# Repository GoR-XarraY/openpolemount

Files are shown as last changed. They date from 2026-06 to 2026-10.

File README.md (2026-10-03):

# OpenPoleMount





**An open-source, 3D-printable universal equipment cradle — and an open mounting standard for home IV poles.**

### 🎉 Certified Open Source Hardware

Every cradle in the line is certified by the [Open Source Hardware Association](https://certification.oshwa.org/):

| | Hardware | OSHWA UID | Certified |
|---|---|---|---|
| [OSHW US002864](https://certification.oshwa.org/us002864.html) | IV Pole Cradle v3 (current) | [US002864](https://certification.oshwa.org/us002864.html) | 2026-10-03 |
| [OSHW US002863](https://certification.oshwa.org/us002863.html) | IV Pole Cradle v2 (Universal Holder) | [US002863](https://certification.oshwa.org/us002863.html) | 2026-10-03 |
| [OSHW US002862](https://certification.oshwa.org/us002862.html) | IV Pole Accessory Box (v1) | [US002862](https://certification.oshwa.org/us002862.html) | 2026-10-03 |
| [OSHW US002834](https://certification.oshwa.org/us002834.html) | IV Pole Cradle (first listing) | [US002834](https://certification.oshwa.org/us002834.html) | 2026-07-10 |

OSHWA certifies that the design is open (public sources, open licenses). It is not a
safety or medical certification. Details: [openpolemount.com/certification](https://openpolemount.com/certification/)

> **This is not a business — it's an open-source hardware project.** Every file is
> free. The goal is that anyone who needs a cradle can print one themselves. A
> print-on-demand option exists so people without a printer aren't left out.

> ⚠️ **NOT A MEDICAL DEVICE — REFERENCE DESIGN ONLY.** OpenPoleMount is
> general-purpose mounting hardware provided for informational and educational
> purposes. It is **not** intended to deliver, control, or support medication or
> therapy, and it has **not** been evaluated or cleared by the FDA or any
> regulatory body. See [DISCLAIMER.md](DISCLAIMER.md) before use.

---

## What It Is

OpenPoleMount is a printed cradle that clamps to a standard home IV pole to hold
equipment. The mounting section — the **OpenPoleMount block** — is an open
standard, so any community-designed accessory can attach to any compatible home
IV pole.

The project began when a home-care caregiver couldn't source a mounting cradle
and printed their own. The files are shared freely so others can do the same.

## Versions

**v3 — current, recommended.** A smaller, more form-fitting cradle refined from
user feedback, built around the OpenPoleMount block standard. The cradle holds
equipment on the pole with the front face accessible, and a printed T-handle
thumbscrew clamps it to a standard home IV pole.

> v3's print files are now available — download the
> [v3 STL](https://github.com/GoR-XarraY/openpolemount/raw/main/stl/OpenPoleMount_IV-Pole_v3.stl)
> or see [openpolemount.com/iv-pole-v3](https://openpolemount.com/iv-pole-v3/) for details.

**v2 — universal device holder.** Fully released and print-ready. Documented as a
universal holder (may fit a range of equipment; no confirmed compatibility list
yet — fit reports welcome). This is the version currently available via
print-on-demand.

**v1 — legacy.** Best repurposed as a pole-mounted accessory box that mounts
below the cradle.

## Specifications

Printed-part dimensions and a starting load rating. **Match your equipment's own
size and weight to these figures before printing** — if it fits the envelope, it
fits the cradle.

| Part | Printed size (L × W × H) | Load rating* |
|---|---|---|
| Equipment cradle v3 | ~125 × 100 × 66 mm | up to ~1.4 kg (3 lb) |
| Equipment cradle v2 | ~126 × 105 × 65 mm | up to ~1.4 kg (3 lb) |
| Pole mounting block | ~60 × 58 × 48 mm | — |

\* *Starting point, not a guarantee. Actual capacity depends on your material,
print settings, and print quality — see the [Print Guide](https://openpolemount.com/iv-pole-v3/print-settings/)
and [DISCLAIMER.md](DISCLAIMER.md). Verify safe support of your own load before use.*

## Community Fit Reports

> The notes here are **user-reported, not manufacturer claims, and not verified
> for any medical use.** OpenPoleMount makes no compatibility guarantee. Confirm
> fit, load suitability, and safety yourself before any use, and consult your
> healthcare provider before using any mount with medical equipment.

Makers have reported that the v3 and v2 form factors fit some home infusion
equipment (including units labeled Curlin CMS6000). We do not maintain or
guarantee a compatibility list. To share a fit report, please
[open an issue](https://github.com/GoR-XarraY/openpolemount/issues).

## Files

| File | Description |
|---|---|
| [`stl/OpenPoleMount_IV-Pole_v3.stl`](https://github.com/GoR-XarraY/openpolemount/raw/main/stl/OpenPoleMount_IV-Pole_v3.stl) | **Equipment cradle v3** — current design, form-fitted (available now) |
| `stl/OpenPoleMount_IV-Pole_v2.stl` | Equipment cradle v2 — universal device holder, available now (print 1x) |
| `stl/thumbscrew_v14_flat_Thandle.stl` | Thumbscrew for pole attachment (print 1x) |
| `stl/OpenPoleMount_IV-Pole_v1.stl` | v1 — legacy; best used as a pole-mounted accessory box |
| [`source/`](source/) | Native editable source files — Blender `.blend` for every design |

## Quick Start

1. **Download** the STL files from [Releases](https://github.com/GoR-XarraY/openpolemount/releases/latest)
2. **Print** the v3 cradle in PLA — see the [v3 Print Guide](https://openpolemount.com/iv-pole-v3/print-settings/); the [v2 Print Guide](https://openpolemount.com/iv-pole-v2/print-settings/) is available too
3. **Assemble** — see the [v3 Assembly Guide](https://openpolemount.com/iv-pole-v3/assembly/)
4. **Read the disclaimer** — [DISCLAIMER.md](DISCLAIMER.md)

No printer? v3 (PETG) and v2 (PLA) can be printed on demand and shipped via
Slant 3D / Teleport — see [openpolemount.com/order](https://openpolemount.com/order/).

## Website & Documentation

**[openpolemount.com](https://openpolemount.com)** — full documentation, print
guide, assembly instructions, safety information

## Licensing

| Asset | License |
|---|---|
| Hardware (STL, STEP, CAD files) | [CERN-OHL-W-2.0](LICENSE) — derivatives must stay open |
| Documentation (docs/, README, images) | [CC-BY-SA-4.0](LICENSE-docs) |

## Contributing

Have an idea for a new IV pole accessory? See [CONTRIBUTING.md](CONTRIBUTING.md).

The OpenPoleMount block mounting standard is designed so any community-designed
accessory can attach to any compatible IV pole mount.

## Community

- [Printables listing](https://www.printables.com) *(link coming soon)*
- Open an [Issue](https://github.com/GoR-XarraY/openpolemount/issues) with questions or problems

---

*OpenPoleMount is an independent open source project. It is not affiliated with
Curlin Medical, Smiths Medical, Moog, or any IV pump manufacturer.*

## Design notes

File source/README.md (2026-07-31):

# Source CAD Files

This folder contains the **native, editable source files** for the OpenPoleMount
hardware designs. The designs are made in [Blender](https://www.blender.org/) —
free, open-source software — so anyone can open, edit, and remix these files
without buying CAD software.

## Files

| File | Design |
|---|---|
| `OpenPoleMount_IV-Pole_v3.blend` | IV Pole Cradle v3 (current, form-fitting) |
| `OpenPoleMount_IV-Pole_v2.blend` | IV Pole Cradle v2 (universal holder) |
| `OpenPoleMount_IV-Pole_v1.blend` | v1 (accessory box) |
| `OpenPoleMount_Pole_Mounting_Block_V1.blend` | Pole Mounting Block |
| `OpenPoleMount_Pole_THandle_Thumbscrew.blend` | T-handle thumbscrew (shared by all designs) |

The ready-to-print STL meshes exported from these sources live in [`stl/`](../stl/).

## Why Source Files Matter

Publishing editable source files (not just STL) is a requirement of true open
source hardware. STL files are like a PDF — anyone can read them but nobody can
easily edit them. These `.blend` files are the original documents — fully editable.

This satisfies the editable-source expectation of
[OSHWA certification](https://certification.oshwa.org), using an open-source
toolchain end to end.

## Editing

Open in Blender 3.x or newer. Units are millimeters at real-world scale — verify
scale before exporting STL for print (File → Export → STL, apply modifiers).
Derivatives are welcome under the hardware license
([CERN-OHL-W-2.0](https://cern-ohl.web.cern.ch/)) — see
[Contributing](https://openpolemount.com/contributing/).

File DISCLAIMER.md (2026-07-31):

# Disclaimer and Liability Notice

## This Is a Reference Design, Not a Medical Device

OpenPoleMount is an open-source reference design for a 3D-printable IV pole
mounting accessory. It is **not** a medical device, and it has **not** been
evaluated, cleared, or approved by the U.S. Food and Drug Administration (FDA)
or any other regulatory body.

## No Warranty

THE OPENPOLEMOUNT DESIGNS, FILES, AND DOCUMENTATION ARE PROVIDED "AS IS,"
WITHOUT WARRANTY OF ANY KIND, EXPRESS OR IMPLIED, INCLUDING BUT NOT LIMITED TO
WARRANTIES OF MERCHANTABILITY, FITNESS FOR A PARTICULAR PURPOSE, SAFETY,
REGULATORY COMPLIANCE, OR NON-INFRINGEMENT.

## Your Responsibility

By using, printing, assembling, or deploying any OpenPoleMount design, you
acknowledge and agree that:

1. **You are solely responsible** for verifying the mechanical integrity,
   dimensional accuracy, material suitability, and safe use of any parts
   you print or assemble.

2. **You must verify that printed parts can safely support the intended load.**
   A typical home infusion device with a full IV bag weighs approximately
   1.4 kg (3 lb). Parts must be printed with appropriate materials and infill to
   safely support the weight of whatever you mount. See the [Print Guide](https://openpolemount.com/iv-pole-v3/print-settings/)
   for minimum recommended settings — these are starting points, not guarantees.

3. **This design is a reference only.** It has not been load-tested under
   clinical conditions. Real-world loads, print quality variations, material
   degradation, and installation errors can all affect safety.

4. **Consult a qualified healthcare professional** before using any accessory
   with medical equipment or in a clinical or home-care setting.

## No Medical Advice

Nothing in this project constitutes medical advice, clinical guidance, or a
recommendation for patient care. Always follow your healthcare provider's
instructions for the safe use of your infusion pump and IV pole.

## Limitation of Liability

To the maximum extent permitted by law, the OpenPoleMount project contributors
shall not be liable for any direct, indirect, incidental, special, consequential,
or punitive damages arising from the use or inability to use these designs,
including but not limited to personal injury, equipment damage, or treatment
interruption.

## Regulatory Note

Depending on your jurisdiction and intended use, 3D-printed accessories for
medical equipment may be subject to local regulations. You are responsible for
determining and complying with any applicable regulations in your area.

---

*If you have questions about safe use, consult your healthcare provider, infusion
pump manufacturer, or a licensed biomedical engineer.*

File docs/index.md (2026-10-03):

# OpenPoleMount

**An open-source, 3D-printable universal equipment cradle — and an open mounting standard for home IV poles.**

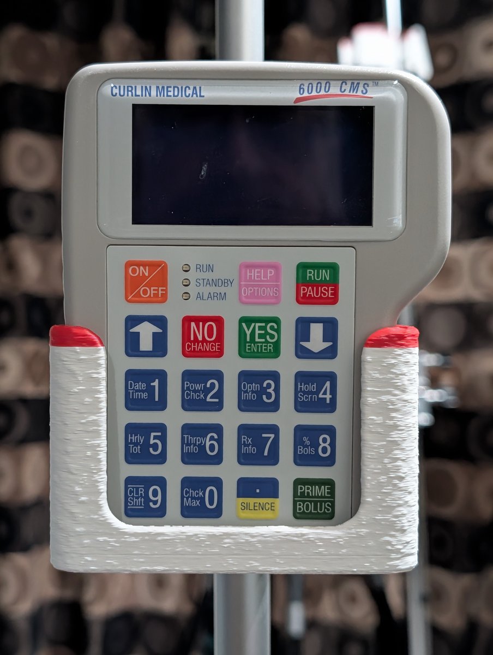
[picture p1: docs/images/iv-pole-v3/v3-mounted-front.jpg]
Compact device seated in the OpenPoleMount v3 cradle on a home IV pole

*The current design — **IV Pole Cradle v3** — a smaller, more form-fitting cradle, refined from feedback on v2.*

<div style="display:flex;flex-wrap:wrap;align-items:center;gap:1rem 1.5rem;padding:1.25rem 1.4rem;margin:1.5rem 0;border-radius:12px;border:2px solid #FF4444;background:var(--md-code-bg-color);">
  <a href="certification/" style="flex:none;display:block;background:#fff;border-radius:10px;padding:10px;">
    OSHW certification mark US002864
  </a>
  <div style="flex:1 1 18rem;">
    <div style="font-size:1.35rem;font-weight:800;line-height:1.25;">🎉 Certified Open Source Hardware</div>
    <div style="margin:0.35rem 0 0.6rem;color:var(--md-default-fg-color--light);">
      The v3 cradle, the v2 universal holder and the v1 accessory box are all certified by the
      <strong>Open Source Hardware Association</strong> —
      <a href="https://certification.oshwa.org/us002864.html">US002864</a>,
      <a href="https://certification.oshwa.org/us002863.html">US002863</a>,
      <a href="https://certification.oshwa.org/us002862.html">US002862</a> and
      <a href="https://certification.oshwa.org/us002834.html">US002834</a>.
    </div>
    <a href="certification/" class="md-button md-button--primary">See the certifications</a>
  </div>
</div>

---

!!! note "This is not a business — it's an open-source hardware project"
    Every file here is free. The goal is simple: that anyone who needs a cradle can
    **print one themselves**, and that the community can build on the design. There is
    nothing to buy to use this project. A print-on-demand option exists so people
    **without a printer** aren't left out.

!!! warning "Reference Design — Not a Medical Device"
    These files are provided for informational and educational purposes only.
    This design is not FDA-cleared or approved. You are responsible for
    verifying the mechanical integrity of any printed parts before use.
    [Read the full disclaimer →](safety.md)

---

## The Problem

Mounting cradles for home infusion equipment can be hard to source, and the bag
alternative many pharmacies send is awkward for anyone who isn't an experienced
nurse. Many home-healthcare users need a reliable, easy-to-use mounting solution
now.

## The Solution — IV Pole Cradle v3

An open-source cradle that any maker can print and any user can assemble.
**v3 is the current, recommended design**: a smaller, more form-fitting redesign
built from feedback on v2 — equipment seats in the pocket with the front face
accessible, and a printed T-handle thumbscrew clamps it to a standard home IV
pole. The mounting section is built as the **[OpenPoleMount
block](mounting-block/index.md)** — the project's foundational component and a
universal standard for any accessory on a home IV pole.

[See all v3 photos & details →](iv-pole-v3/index.md){ .md-button .md-button--primary }

### The v3 model

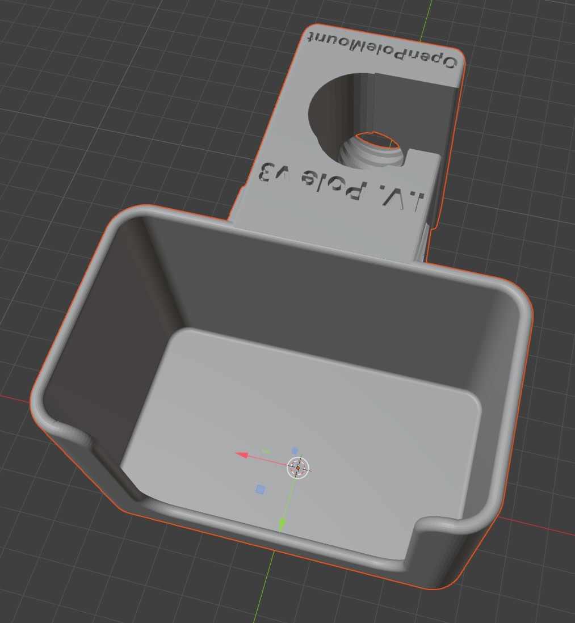
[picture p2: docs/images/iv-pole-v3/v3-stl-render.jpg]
IV Pole Cradle v3 — 3D render, form-fitting equipment pocket at left, U-shaped pole channel at right

*IV Pole Cradle v3 — form-fitting equipment pocket at left, U-shaped pole channel and thumbscrew boss at right, "I.V. Pole v3" embossed on the body.*

---

## Get the v3 cradle

The whole point of this project is **open-source 3D printing**. Printing it
yourself is the primary path — it's free, and you control the material and quality.

<div style="padding:2rem;background:var(--md-code-bg-color);border-radius:8px;border-left:5px solid var(--md-primary-fg-color);margin:1.5rem 0;">
  <div style="font-size:1.35rem;font-weight:800;margin-bottom:0.5rem;">🖨️ Print it yourself — free & open source</div>
  <div style="font-size:0.95rem;color:var(--md-default-fg-color--light);margin-bottom:1.25rem;max-width:48rem;">
    Download the [v3 STL files](https://github.com/GoR-XarraY/openpolemount/raw/main/stl/OpenPoleMount_IV-Pole_v3.stl) and print on any FDM printer. Tested
    settings carried over from v1/v2 in PLA. Two parts: the cradle body and the
    T-handle thumbscrew — no extra hardware needed.
  </div>
  <a href="iv-pole-v3/print-settings/" style="display:inline-block;padding:0.6rem 1.5rem;background:var(--md-primary-fg-color);color:white;border-radius:4px;text-decoration:none;font-size:1rem;font-weight:700;">Print Guide (v3) →</a>
</div>

<div style="padding:1.25rem 1.5rem;background:var(--md-code-bg-color);border-radius:8px;border-left:4px solid #888;margin:1rem 0;">
  <div style="font-size:1rem;font-weight:700;margin-bottom:0.35rem;">📦 No printer nearby? Order a print.</div>
  <div style="font-size:0.875rem;color:var(--md-default-fg-color--light);margin-bottom:0.85rem;">
    The <strong>v3</strong> cradle + thumbscrew can be printed in PETG and shipped
    via <strong>Slant 3D / Teleport</strong> (v2 in PLA too) — a fallback for people
    without printer access.
  </div>
  <a href="order/" style="display:inline-block;padding:0.45rem 1.1rem;background:#555;color:white;border-radius:4px;text-decoration:none;font-size:0.9rem;font-weight:600;">Order a print →</a>
</div>

## Download STL Files

[Download STL Files (latest release)](https://github.com/GoR-XarraY/openpolemount/releases/latest){ .md-button .md-button--primary }
[View on GitHub](https://github.com/GoR-XarraY/openpolemount){ .md-button }

| File | Purpose | Print |
|---|---|---|
| [`OpenPoleMount_IV-Pole_v3.stl`](https://github.com/GoR-XarraY/openpolemount/raw/main/stl/OpenPoleMount_IV-Pole_v3.stl) | **v3 cradle body** — current design, form-fitted pocket | 1× |
| [`OpenPoleMount_IV-Pole_v2.stl`](https://github.com/GoR-XarraY/openpolemount/raw/main/stl/OpenPoleMount_IV-Pole_v2.stl) | v2 cradle body — universal device holder, available now | 1× |
| [`thumbscrew_v14_flat_Thandle.stl`](https://github.com/GoR-XarraY/openpolemount/raw/main/stl/thumbscrew_v14_flat_Thandle.stl) | T-handle thumbscrew for pole attachment | 1× |

## Getting Started

1. **[See the v3 cradle →](iv-pole-v3/index.md)** — photos, model, and details
2. **[Print it yourself →](iv-pole-v3/print-settings.md)** — settings, orientation, checklist
3. **[Assemble it →](iv-pole-v3/assembly.md)** — step-by-step mounting (no tools)
4. **[Safety & Disclaimer →](safety.md)** — read before use

## Designed For

| Component | Description |
|---|---|
| Equipment | A compact device that fits the pocket envelope (~125 × 100 × 66 mm, up to ~1.4 kg / 3 lb) |
| Pole | Standard home IV pole (~25 mm / 1 inch diameter) |
| Attachment | Printed T-handle thumbscrew (included in download) |

## Open Source — Build On It

All designs are released under [CERN-OHL-W-2.0](https://cern-ohl.web.cern.ch/) —
any modifications must stay open source. Documentation is under
[CC-BY-SA-4.0](https://creativecommons.org/licenses/by-sa/4.0/). This is community
hardware: improvements, remixes, and new accessories are the goal.

**[Contribute a new accessory →](contributing.md)**

---

## Looking for v2?

**v2** is still fully released and print-ready — it's now documented as a
**universal device holder**: its more open pocket may fit a range of similar-sized
equipment, though we don't yet have a confirmed compatibility list. It's also the version currently available via print-on-demand order.

**[About the v2 universal holder →](iv-pole-v2/index.md)**

## Looking for v1?

The original **v1** print is still available, but it's **not functional as an
equipment cradle** — the device's buttons and screen are not accessible when it's
seated in v1. v1 is best repurposed as an **accessory box that mounts on the pole
below the cradle** — for alcohol wipes, spare caps, tubing, or other small supplies.

**[About the v1 accessory box →](print-settings.md)**

---

*OpenPoleMount is an independent open-source project. It is not affiliated with
Curlin Medical, Smiths Medical, or any IV pump manufacturer.*

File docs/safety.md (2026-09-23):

# Safety & Disclaimer

## ⚠️ This Is a Reference Design, Not a Medical Device

OpenPoleMount is an open-source reference design. It is **not** a medical device
and has **not** been evaluated, cleared, or approved by the FDA or any other
regulatory body.

**By printing or using this design, you accept full responsibility for verifying
its safety and suitability for your specific situation.**

---

## Full Disclaimer

THE OPENPOLEMOUNT DESIGNS, FILES, AND DOCUMENTATION ARE PROVIDED "AS IS,"
WITHOUT WARRANTY OF ANY KIND. THE OPENPOLEMOUNT PROJECT AND ITS CONTRIBUTORS
MAKE NO WARRANTIES AND ACCEPT NO LIABILITY FOR ANY USE OF THESE DESIGNS,
INCLUDING BUT NOT LIMITED TO PERSONAL INJURY, EQUIPMENT DAMAGE, OR TREATMENT
INTERRUPTION.

See [DISCLAIMER.md](https://github.com/GoR-XarraY/openpolemount/blob/main/DISCLAIMER.md)
for the complete legal disclaimer.

---

## Before First Use — Safety Checklist

Work through this checklist every time before mounting equipment:

**Print quality:**

- [ ] Parts printed to the recommended minimums — ≥1 mm walls, ≥1 mm top/bottom, ≥25% non-concentric infill (grid is fine) — see the [Print Guide](iv-pole-v3/print-settings.md)
- [ ] No visible layer delamination — parts do not flex or crack under firm hand pressure
- [ ] No significant warping — base and pole channel are flat and straight
- [ ] Thumbscrew threads are clean, smooth, and undamaged

**Fit and function:**

- [ ] Thumbscrew engages cleanly and holds firm under hand pressure
- [ ] Cradle mounted on pole — does not slide under firm downward push
- [ ] Device seats fully in the cradle without rocking or side movement
- [ ] Any tubing or cabling exits the device without creating tension on the mount

**Environment:**

- [ ] IV pole base is fully spread and stable on the floor
- [ ] Floor surface is stable (not sloped or slippery)
- [ ] Caregiver or nurse has reviewed the complete setup

---

## Who to Contact

| Question | Contact |
|---|---|
| Equipment use and care | Your equipment supplier or home health agency |
| IV pole setup | Your home health nurse |
| Print quality issues | [Open a GitHub issue](https://github.com/GoR-XarraY/openpolemount/issues) |
| Medical safety questions | Your healthcare provider |

---

## Regulatory Note

In the United States, the FDA regulates 3D-printed objects that are *marketed
as medical devices*. OpenPoleMount publishes open reference designs — it is
not marketed as a finished product or medical device.

However, regulations vary by jurisdiction and intended use. You are responsible
for understanding and complying with any applicable regulations in your area.

If you are a healthcare professional intending to use this design in a clinical
setting, please consult your institution's biomedical engineering department and
compliance officer before use.

---

*Last reviewed: 2026-07-30*

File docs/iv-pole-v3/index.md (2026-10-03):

---
title: IV Pole Mount v3
description: Open source 3D-printable form-fitting equipment cradle for home IV poles
image: images/iv-pole-v3/v3-og-image.jpg
---

# IV Pole Cradle v3

<div style="display:flex;align-items:center;gap:1rem;padding:0.9rem 1rem;margin:1rem 0 1.5rem;border-radius:10px;border:1px solid var(--md-default-fg-color--lightest);">
  <a href="https://certification.oshwa.org/us002864.html" style="flex:none;display:block;background:#fff;border-radius:8px;padding:8px;" title="OSHWA certificate US002864">
    OSHW certification mark US002864
  </a>
  <div><strong>Certified open source hardware</strong> — the IV Pole Cradle v3 is OSHWA certificate
  <a href="https://certification.oshwa.org/us002864.html">US002864</a>.
  <a href="../../certification/">About the certifications →</a></div>
</div>

**The current OpenPoleMount design — a smaller, more form-fitting cradle pocket,
based on feedback from people using v2.**

IV Pole Cradle v3 — 3D render, "I.V. Pole v3" and "OpenPoleMount" embossed on the mounting block
*IV Pole Cradle v3 — a tighter, form-fitting pocket (~125 x 100 x 66 mm printed), with the same U-shaped pole channel and thumbscrew boss as v2.*

---

!!! success "This is the design to print"
    **v3 is the recommended cradle.** It's a smaller, more form-fitting redesign of
    the pocket — built directly from feedback from people who printed v2 — while
    keeping the same pole channel and printed T-handle thumbscrew that clamps it to
    a standard home IV pole. It uses the `thumbscrew_v14_flat_Thandle.stl` thumbscrew
    and the OpenPoleMount block standard, same as v1 and v2.

    [**v2**](../iv-pole-v2/index.md) is still a good print — it's now documented as a
    **universal device holder** for other devices, since its more open
    pocket shape isn't as tightly fitted to any one device.

!!! success "v3 STL files are available now"
    The v3 print files are published and ready to print. Download the
    [v3 cradle STL](https://github.com/GoR-XarraY/openpolemount/raw/main/stl/OpenPoleMount_IV-Pole_v3.stl)
    directly, or see the [Print Guide](print-settings.md) for settings and required files.

## Installed Photos

<div style="display:grid;grid-template-columns:1fr 1fr;gap:1rem;margin:1.5rem 0;">
  <div>
    Equipment cradle v3 — front view, device seated
    <p style="font-size:0.85em;color:#666;margin-top:0.4rem;">Front — the device seats in the pocket with the front face accessible</p>
  </div>
  <div>
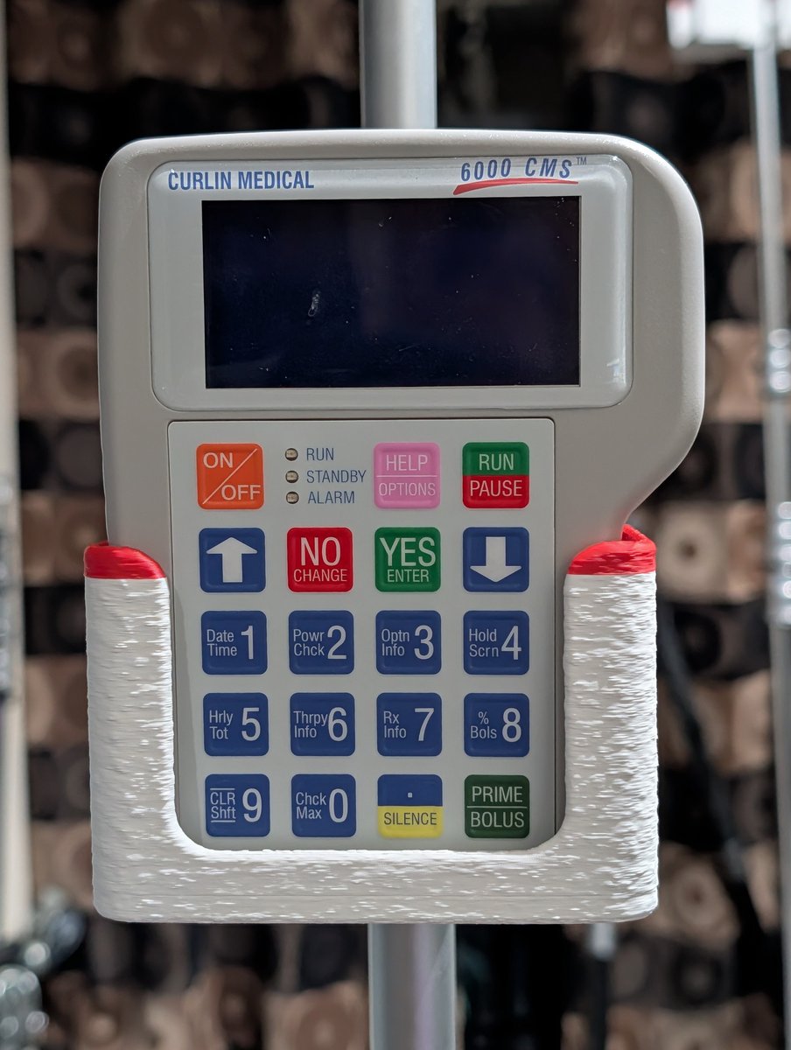
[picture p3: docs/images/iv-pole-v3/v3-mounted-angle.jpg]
V3 mount — 3/4 angle view
    
    <p style="font-size:0.85em;color:#666;margin-top:0.4rem;">3/4 angle — device in the form-fitting cradle pocket</p>
  </div>
  <div>
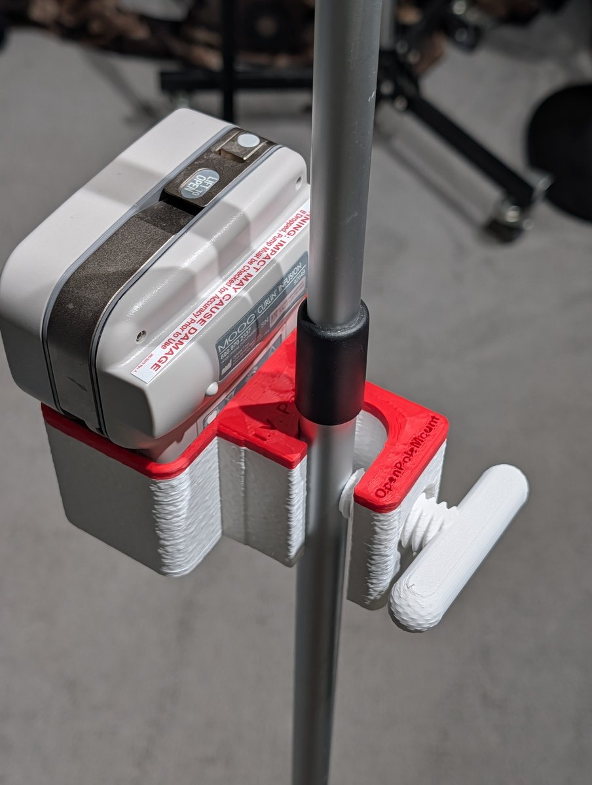
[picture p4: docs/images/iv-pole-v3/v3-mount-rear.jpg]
V3 mount — rear/underside with device cassette door
    
    <p style="font-size:0.85em;color:#666;margin-top:0.4rem;">Rear/underside — device cassette door, "I.V. Pole v3" / "OpenPoleMount" embossed on the block</p>
  </div>
  <div>
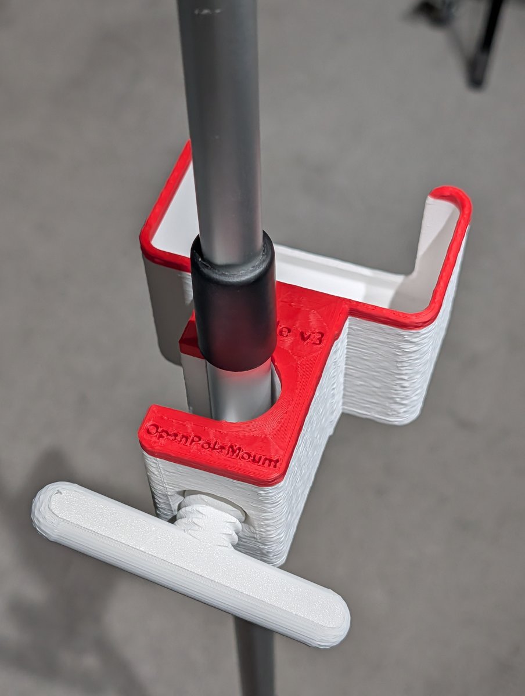
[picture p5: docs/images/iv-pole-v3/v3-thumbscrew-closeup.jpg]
T-handle thumbscrew close-up on V3 mount
    
    <p style="font-size:0.85em;color:#666;margin-top:0.4rem;">Thumbscrew detail — hand-tighten only</p>
  </div>
</div>

### Example Fit — More Views

> User-reported example fit — not a manufacturer claim, not verified for any medical use. Confirm fit yourself before use.

<div style="display:grid;grid-template-columns:1fr 1fr;gap:1rem;margin:1.5rem 0;">
  <div>
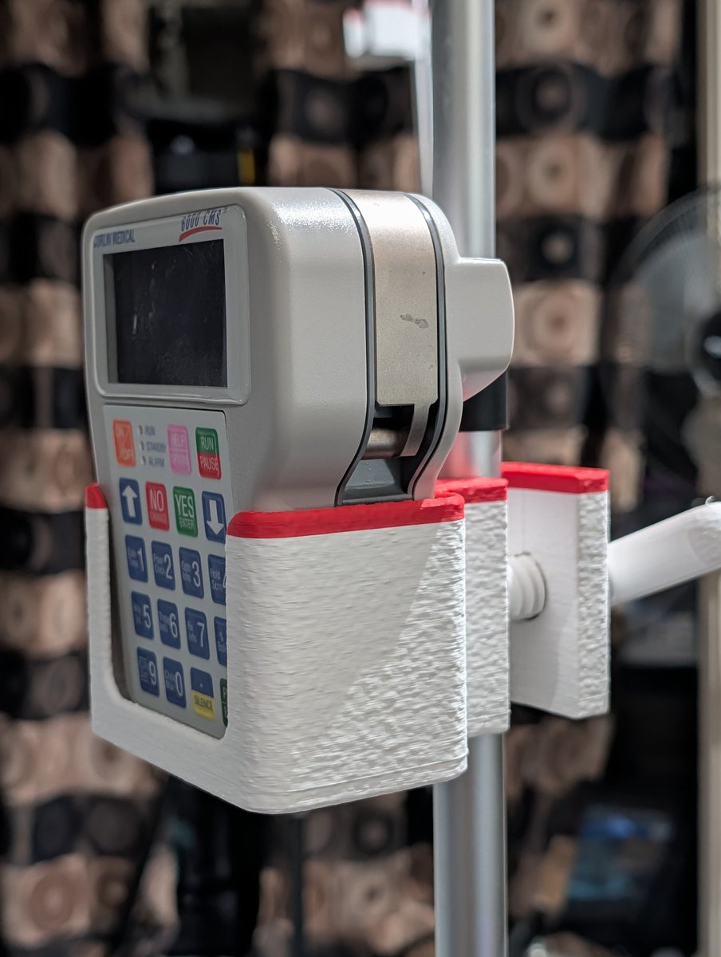
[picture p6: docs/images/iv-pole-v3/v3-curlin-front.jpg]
Curlin CMS6000 front in V3 cradle, alternate angle
    
    <p style="font-size:0.85em;color:#666;margin-top:0.4rem;">Curlin CMS6000 — front, keypad fully visible</p>
  </div>
  <div>
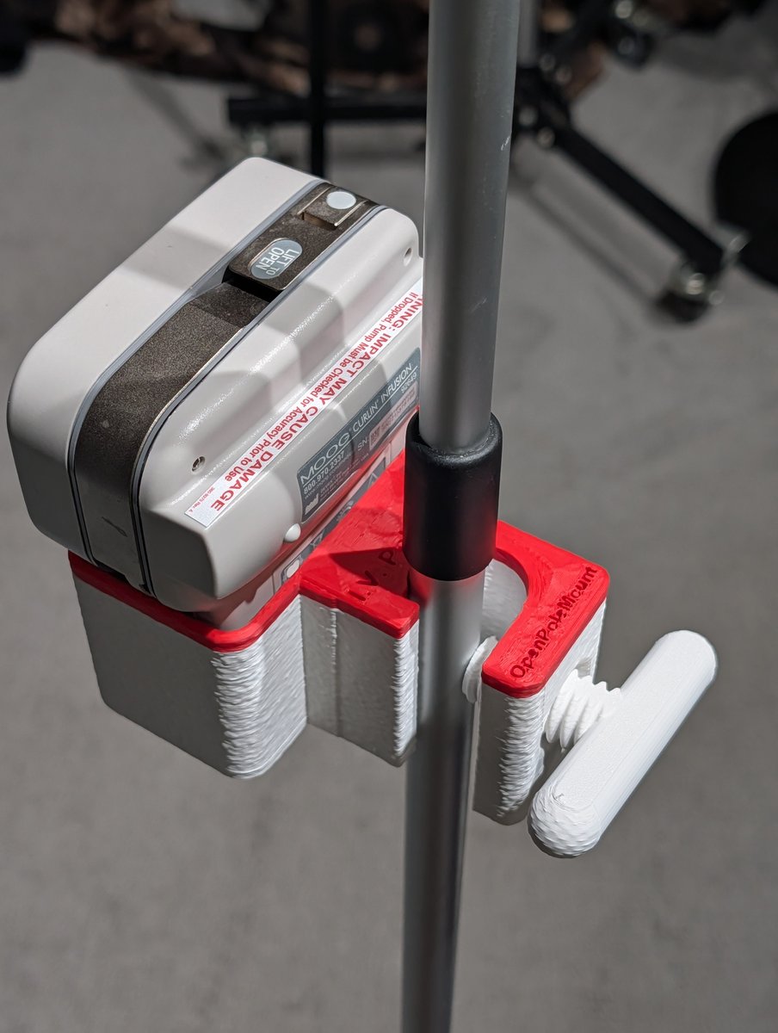
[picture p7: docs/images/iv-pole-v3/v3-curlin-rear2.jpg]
Curlin CMS6000 rear/underside in V3 cradle, alternate angle
    
    <p style="font-size:0.85em;color:#666;margin-top:0.4rem;">Rear/underside — alternate angle, cassette door and pole clamp</p>
  </div>
  <div>
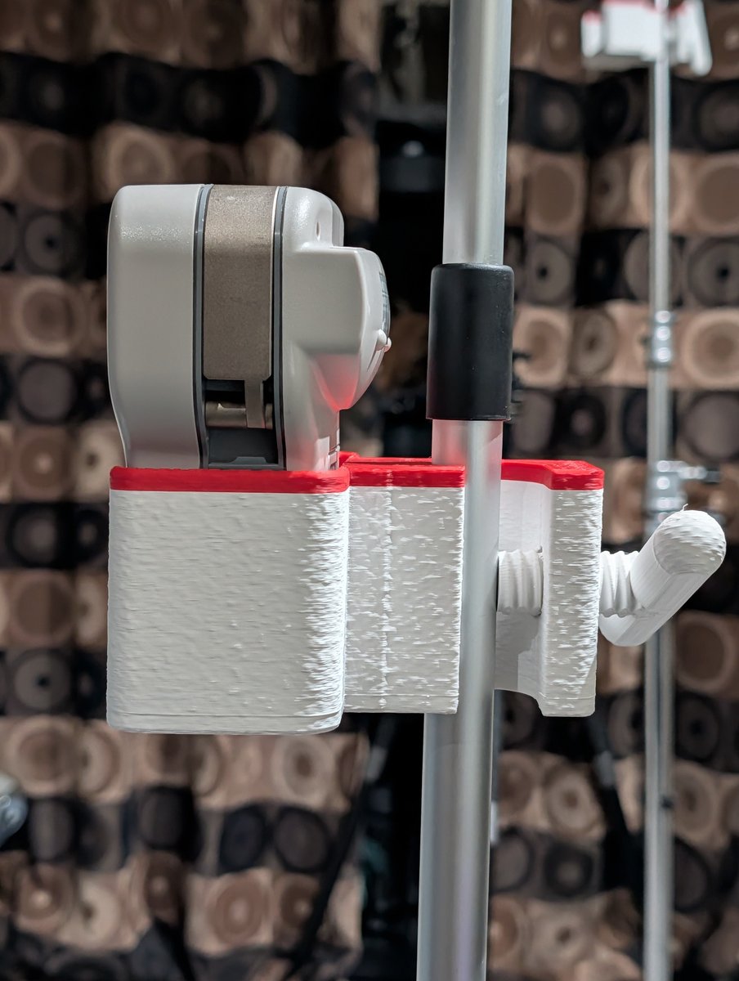
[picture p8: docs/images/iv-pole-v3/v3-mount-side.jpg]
V3 mount — side view showing pole clamp and a second OpenPoleMount block
    
    <p style="font-size:0.85em;color:#666;margin-top:0.4rem;">Side — pole clamp detail; a second OpenPoleMount block mounted below shows the stackable standard</p>
  </div>
</div>

### PETG print — textured finish

A v3 cradle printed in PETG from the [textured-surface STL variant](https://github.com/GoR-XarraY/openpolemount/releases/download/v3.0.0/OpenPoleMount_IV-Pole_v3_textured.stl) — same fit and print settings as the standard body, with the surface texture baked into the mesh.

> User-reported example fit — not a manufacturer claim, not verified for any medical use. Confirm fit yourself before use.

<div style="display:grid;grid-template-columns:1fr 1fr;gap:1rem;margin:1.5rem 0;">
  <div>
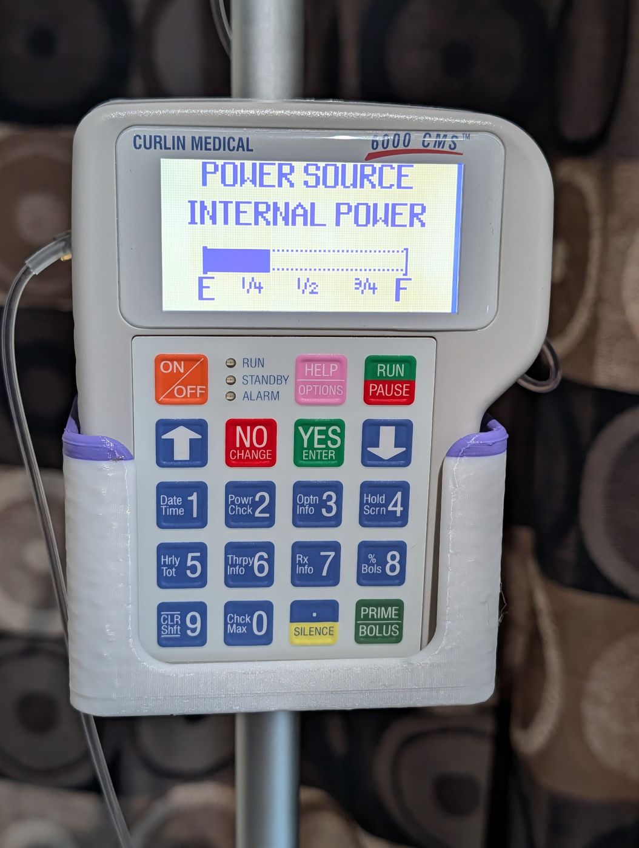
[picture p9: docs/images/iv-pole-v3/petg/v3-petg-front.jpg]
PETG-printed v3 cradle, front view with device in place, textured finish visible
    
    <p style="font-size:0.85em;color:#666;margin-top:0.4rem;">Front view — textured PETG print, same pocket dimensions as the standard PLA cradle</p>
  </div>
  <div>
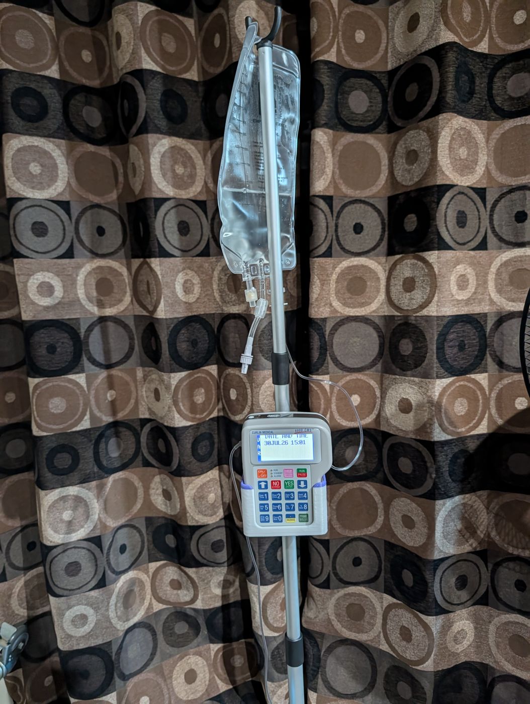
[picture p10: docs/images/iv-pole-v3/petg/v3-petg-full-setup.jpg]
Full IV pole setup with PETG-printed v3 cradle mounted near the base
    
    <p style="font-size:0.85em;color:#666;margin-top:0.4rem;">Full pole setup — PETG cradle mounted on the pole, same clamp and thumbscrew as PLA prints</p>
  </div>
  <div>
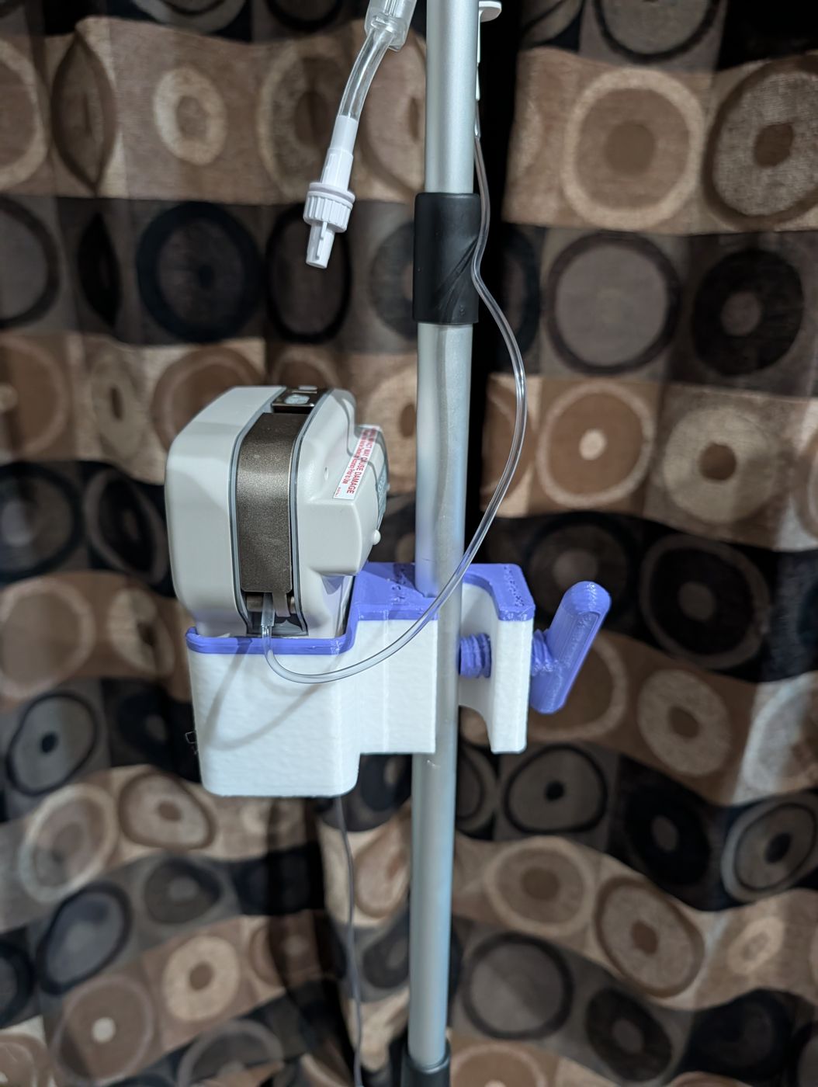
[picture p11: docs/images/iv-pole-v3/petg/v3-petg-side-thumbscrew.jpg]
Side view of PETG v3 cradle showing pole clamp and printed thumbscrew
    
    <p style="font-size:0.85em;color:#666;margin-top:0.4rem;">Side view — printed T-handle thumbscrew and pole clamp, textured PETG surface</p>
  </div>
  <div>
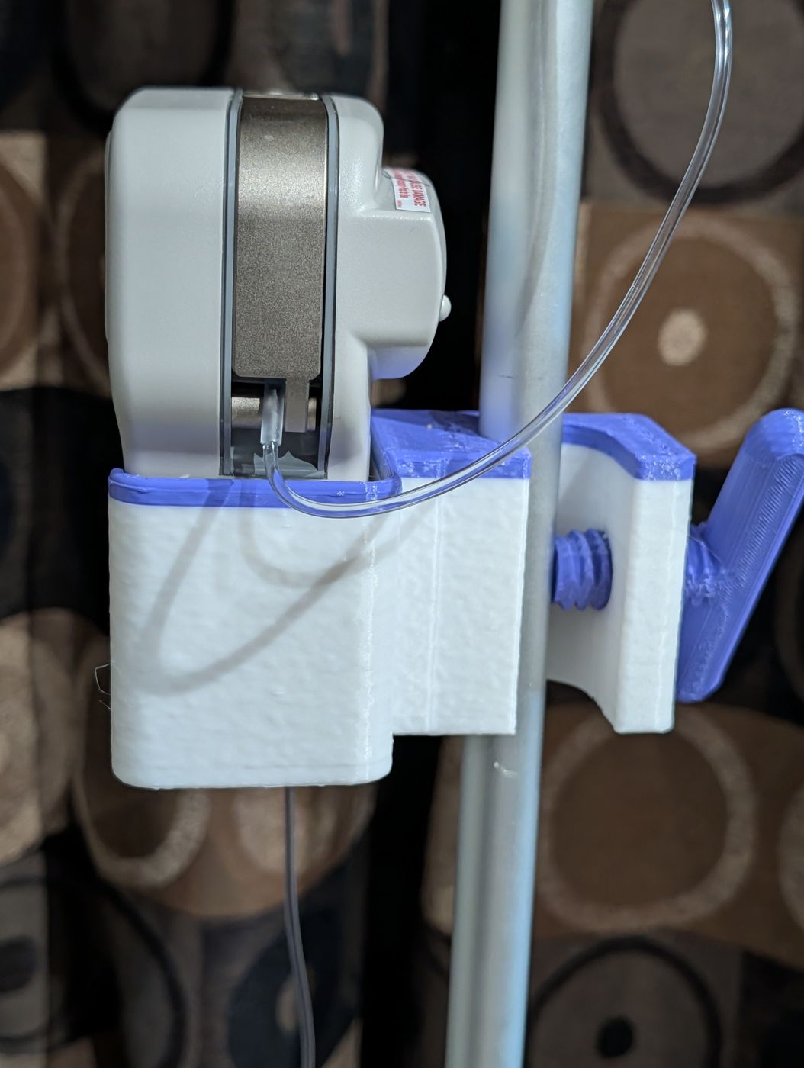
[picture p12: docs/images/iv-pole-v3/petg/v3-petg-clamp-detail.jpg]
Close-up of PETG mounting block and thumbscrew, textured layer lines visible
    
    <p style="font-size:0.85em;color:#666;margin-top:0.4rem;">Mounting block detail — textured build-plate finish on the PETG print, layer lines visible on the clamp</p>
  </div>
  <div>
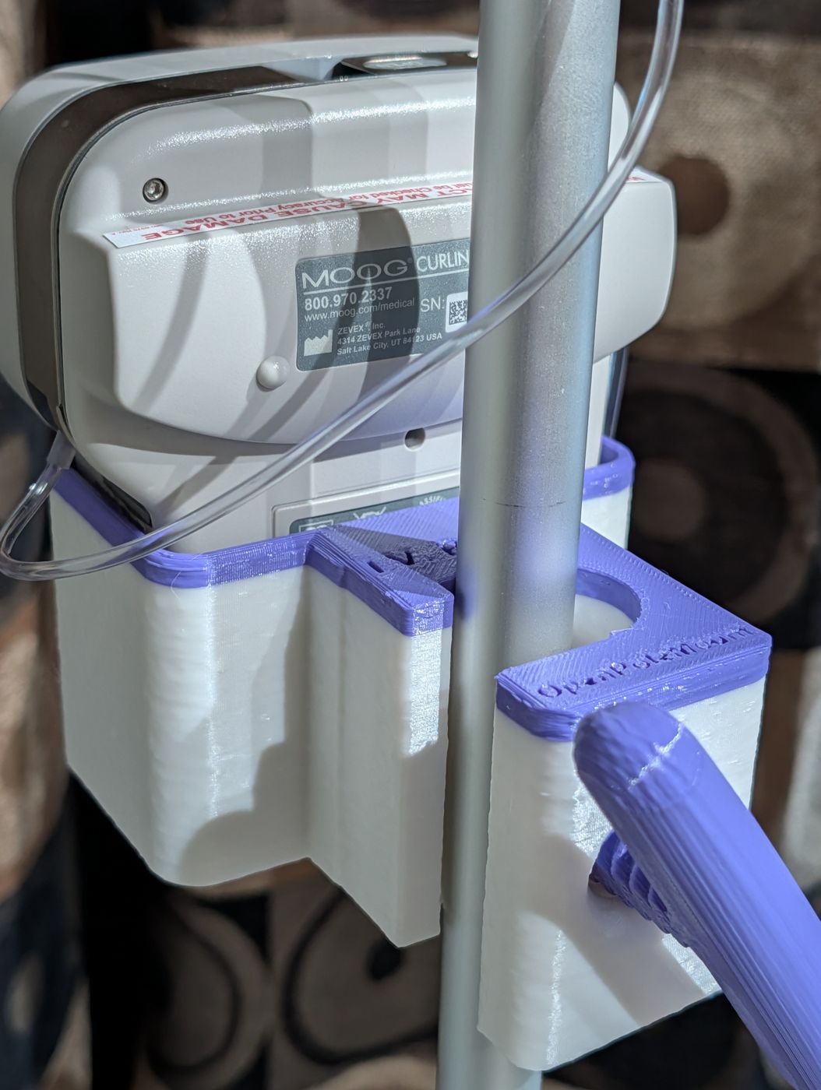
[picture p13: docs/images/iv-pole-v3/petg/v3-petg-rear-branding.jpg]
Rear of PETG v3 cradle showing embossed OpenPoleMount branding on the mounting block
    
    <p style="font-size:0.85em;color:#666;margin-top:0.4rem;">Rear/underside — "OpenPoleMount" embossed on the mounting block, printed in PETG</p>
  </div>
  <div>
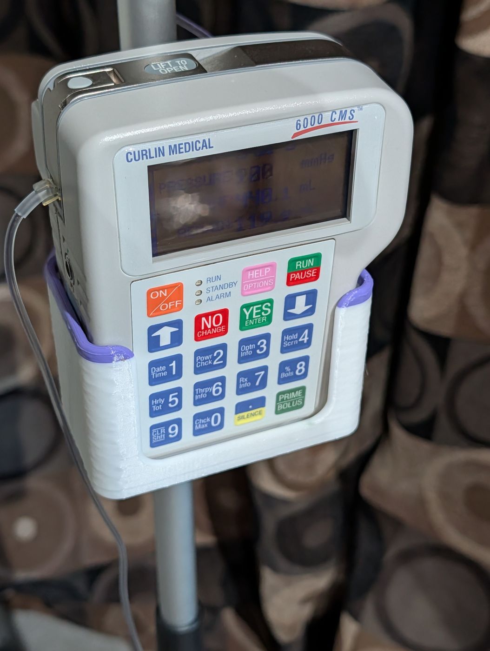
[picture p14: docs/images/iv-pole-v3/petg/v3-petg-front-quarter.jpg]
3/4 angle view of PETG v3 cradle with device seated, textured finish
    
    <p style="font-size:0.85em;color:#666;margin-top:0.4rem;">3/4 angle — device seated in the PETG-printed pocket, textured build-plate finish</p>
  </div>
  <div>
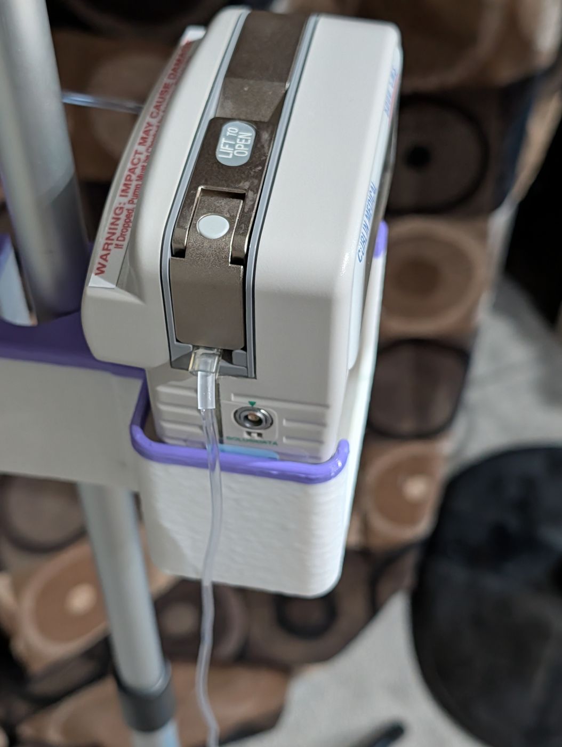
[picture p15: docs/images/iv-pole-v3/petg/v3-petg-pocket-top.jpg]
Close-up of PETG cradle pocket wall and mounting block edge
    
    <p style="font-size:0.85em;color:#666;margin-top:0.4rem;">Pocket wall and mounting block edge — PETG print, textured surface</p>
  </div>
</div>

### Cradle Detail — Empty

<div style="display:grid;grid-template-columns:1fr 1fr;gap:1rem;margin:1.5rem 0;">
  <div>
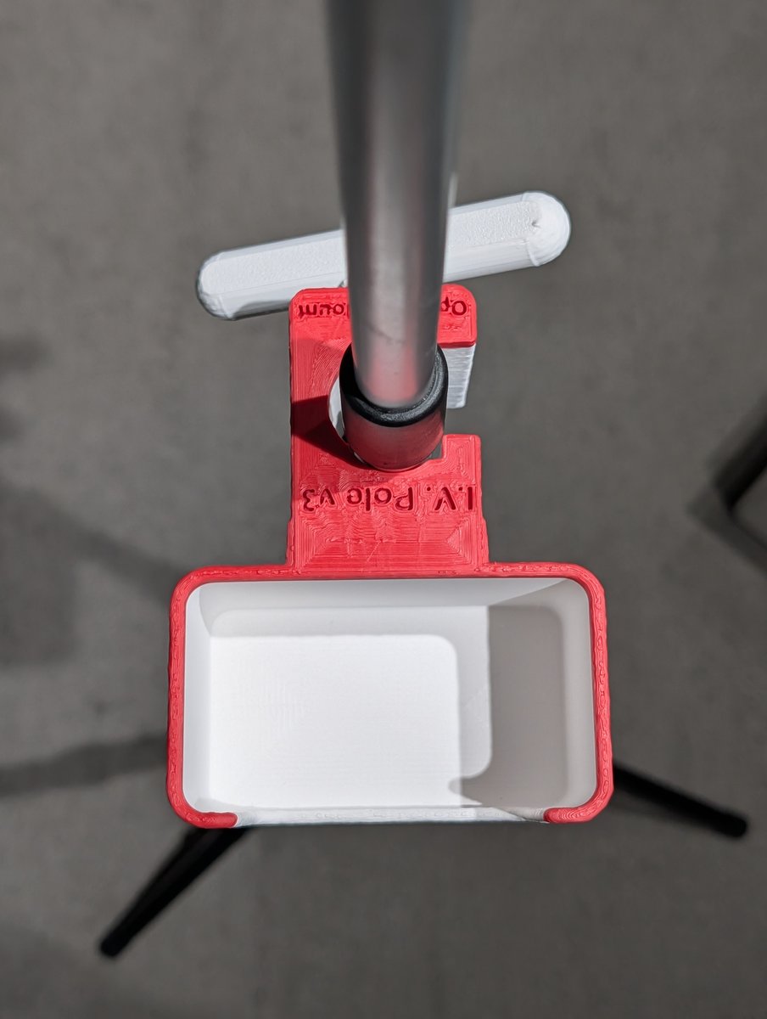
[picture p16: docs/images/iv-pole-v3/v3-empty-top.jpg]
V3 cradle empty — top-down view on pole
    
    <p style="font-size:0.85em;color:#666;margin-top:0.4rem;">Top-down — "I.V. Pole v3" label embossed on the mounting block</p>
  </div>
  <div>
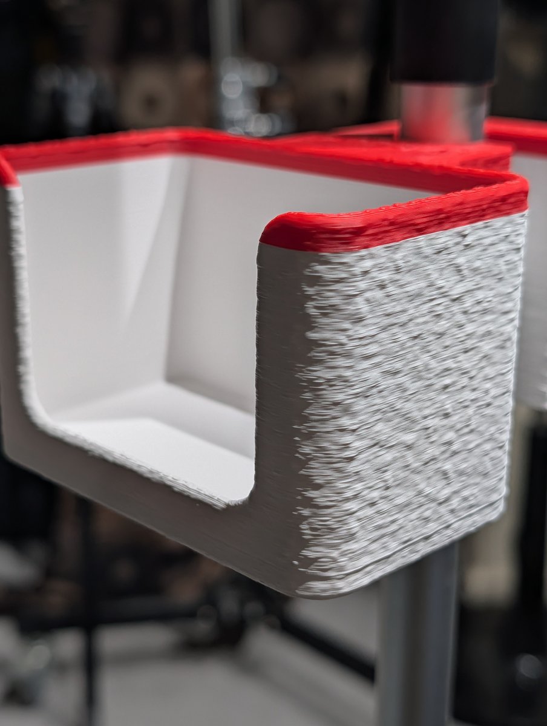
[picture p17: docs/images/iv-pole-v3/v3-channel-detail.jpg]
V3 cradle pocket close-up, empty
    
    <p style="font-size:0.85em;color:#666;margin-top:0.4rem;">Pocket detail — the tighter, form-fitting shape compared to v2's more open box</p>
  </div>
</div>

---

<div style="padding:1.75rem;background:var(--md-code-bg-color);border-radius:8px;border-left:5px solid var(--md-primary-fg-color);margin:2rem 0;">
  <div style="font-size:1.2rem;font-weight:800;margin-bottom:0.5rem;">🖨️ Print it yourself — free & open source</div>
  <div style="font-size:0.9rem;color:var(--md-default-fg-color--light);margin-bottom:1.25rem;">Download the v3 STL files and print on any FDM printer. This is the whole point of the project.</div>
  <a href="../iv-pole-v3/print-settings/" style="display:inline-block;padding:0.55rem 1.4rem;background:var(--md-primary-fg-color);color:white;border-radius:4px;text-decoration:none;font-size:0.95rem;font-weight:700;">Print Guide →</a>
</div>

<div style="font-size:0.85rem;color:var(--md-default-fg-color--light);margin:1rem 0;">
  No printer or maker nearby? v3 can be printed in PETG on demand and shipped via
  Slant 3D / Teleport.
  <a href="../order/">No printer? Order one →</a>
</div>

## Next Steps

1. **[Print Guide →](print-settings.md)** — settings, orientation, checklist
2. **[Assembly →](assembly.md)** — step-by-step with photos
3. **[Safety & Disclaimer →](../safety.md)** — read before use

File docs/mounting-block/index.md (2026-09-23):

---
title: The OpenPoleMount Mounting Block v1
description: The Pole Mounting Block v1 — the foundational, open-source component every OpenPoleMount cradle and accessory is built on.
image: ../images/mounting-block/block-v1-render.jpg
---

# The OpenPoleMount Mounting Block — v1

**The foundation of the whole project.** Every OpenPoleMount design — the v3
cradle, the v2 universal holder, and every future accessory — is built on top of
this one part: the **Pole Mounting Block**. It is the piece that actually clamps
to a standard home IV pole, and it defines the shared interface everything else
attaches to.

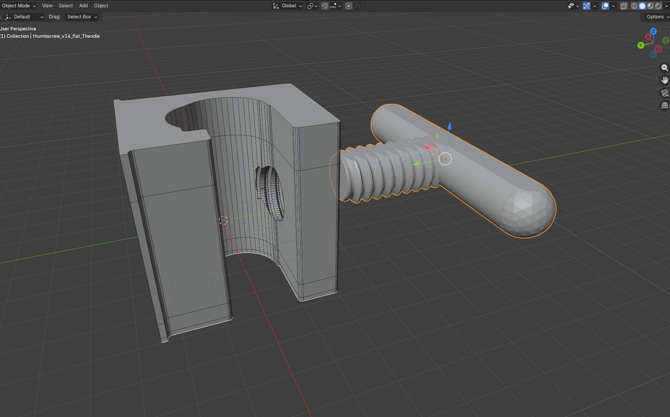
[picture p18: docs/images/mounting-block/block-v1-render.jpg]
OpenPoleMount Pole Mounting Block v1 — 3D render showing the U-shaped pole channel and T-handle thumbscrew clamp

*The Pole Mounting Block v1 with its T-handle thumbscrew — the U-shaped channel wraps a standard IV pole and the printed thumbscrew clamps it in place.*

---

!!! info "This is a base component, not the current cradle"
    If you're here to **print an equipment cradle**, you want the
    [**v3 cradle**](../iv-pole-v3/index.md) (the current design) — the mounting
    block is already built into it. This page documents the block **on its own**,
    as the shared foundation for the project and for people designing their own
    accessories.

!!! warning "Reference Design — Not a Medical Device"
    These files are provided for informational and educational purposes only. This
    is not an FDA-cleared or approved product. It is a load-bearing part; you are
    responsible for verifying the mechanical integrity of anything you print before
    use. [Read the full disclaimer →](../safety.md)

## Why it exists

Rather than redesign a pole clamp for every accessory, OpenPoleMount treats the
pole attachment as **one reusable primitive**. Design any holder, tray, or mount
so it sits on the block, and it inherits a known, tested way of attaching to a
standard home IV pole — and it becomes compatible with everything else in the
system. This is what makes OpenPoleMount an *open hardware platform* rather than a
single part:

- **Users** print one mounting approach and understand it once.
- **Contributors** design to a consistent, documented interface.
- **The ecosystem** grows every time someone adds an accessory to the same block.

## Download the files

!!! danger "Load-bearing part — read the print guide first"
    The block carries the full weight of equipment and a filled IV bag through a
    single thumbscrew clamp. Wall count and infill are **safety-critical**. Use the
    [shared print settings](../iv-pole-v3/print-settings.md) (PLA, ≥1 mm walls, ≥1 mm
    top/bottom, ≥25 % non-concentric infill) as the minimum.

| File | Purpose | Qty |
|---|---|---|
| [`OpenPoleMount_Pole_Mounting_Block_V1.stl`](https://github.com/GoR-XarraY/openpolemount/raw/main/stl/OpenPoleMount_Pole_Mounting_Block_V1.stl) | The mounting block (pole clamp + accessory interface) | 1 |
| [`OpenPoleMount_Pole_Mounting_Block_ThandleThumbscrew-V1.stl`](https://github.com/GoR-XarraY/openpolemount/raw/main/stl/OpenPoleMount_Pole_Mounting_Block_ThandleThumbscrew-V1.stl) | Printed T-handle thumbscrew that clamps the block to the pole | 1 |

Native editable source CAD (Blender `.blend`) lives in the repository's
[`source/`](https://github.com/GoR-XarraY/openpolemount/tree/main/source) folder
(`OpenPoleMount_Pole_Mounting_Block_V1.blend`); the STL meshes above are the
print-ready exports. Both are remixable under the hardware license.

## Dimensions

Overall printed footprint, measured directly from the STL geometry:

| Part | Bounding size (X × Y × Z) |
|---|---|
| Pole Mounting Block v1 | **48.0 × 57.9 × 59.5 mm** |
| T-handle Thumbscrew v1 | **102.0 × 53.0 × 16.0 mm** (T-handle across × head × thickness) |

!!! note "Formal interface spec — pending"
    The exact **accessory-mating dimensions** (bolt/boss pattern, thumbscrew
    thread pitch, and the pole-channel diameter range) are what a contributor needs
    to design a guaranteed-compatible accessory. Those are being documented from the
    source CAD and are **not yet published as a formal tolerance spec** — the
    numbers above are the outer bounding box only. If you want to start designing an
    accessory now, [open an issue](https://github.com/GoR-XarraY/openpolemount/issues)
    and we'll share the working interface dimensions directly.
    *(Pending George's confirmation before this can be published as an official spec.)*

## Printing it

The block prints on the same conservative, PLA-validated settings as the rest of
the design family — see the **[shared print guide](../iv-pole-v3/print-settings.md)**.
Print the block with the pole channel vertical so the layer lines run
perpendicular to the clamping load, and print the T-handle thumbscrew flat, handle
face down, no supports required.

!!! warning "Testing status"
    The published [destruction testing](../testing.md) was performed on the
    v1/v2 cradle body, which uses this same block and thumbscrew interface. The
    block's clamp geometry is therefore covered by that testing, but the block has
    not been separately logged as its own test article. Treat the shared minimums as
    a floor and inspect every print before use. *(Pending George's standalone
    block test log before this is stated as an independent tested claim.)*

## Building on the block

Designing an accessory? Start from this part, keep the pole-channel and thumbscrew
interface unchanged, and add your holder on top. See
[Contributing](../contributing.md) and the
[Accessories](../accessories/index.md) page — anything built to this block works
with every OpenPoleMount cradle.

!!! tip "License note — you keep your accessory; just keep block changes open"
    The block is licensed **CERN-OHL-W-2.0 (weakly reciprocal)**. In practice: if
    you **modify the block itself**, your modified block must stay open under the
    same license. But a **separate accessory** you design to sit on top of the
    block does **not** have to be open — you can license your own add-on however
    you like. Improve the foundation in the open; your accessory stays yours.

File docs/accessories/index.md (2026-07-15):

# Accessories

Community-designed accessories for the OpenPoleMount block system.

---

!!! info "Be the First"
    No accessories yet — be the first to contribute!

    The OpenPoleMount block is a universal mounting interface for any
    accessory on a standard home IV pole. Design your accessory to
    attach to the block and it will be compatible with all future mounts.

    **[Learn how to contribute →](../contributing.md)**

---

## The OpenPoleMount Block Standard

Any accessory that interfaces with the OpenPoleMount block can be mounted on
any compatible IV pole mount using the same thumbscrew attachment.

This means:

- **Users** only need one mount, then can swap accessories
- **Contributors** design for a known, consistent interface
- **The ecosystem** grows with every new accessory

### Dimensional Specification

The mounting block now has its own page: **[The Mounting Block (Project
Foundation)](../mounting-block/index.md)** — with the STL, source CAD, and
measured dimensions. The formal accessory-mating tolerance spec (thread pitch,
boss pattern, channel diameter) is still being finalized there.

If you want to start designing now, [open an issue](https://github.com/GoR-XarraY/openpolemount/issues)
and we'll share the current interface dimensions.

---

## Planned Official Accessories

| Accessory | Status |
|---|---|
| IV bag holder / spike stand | Planned |
| Universal phone / tablet mount | Planned |
| [OpenPoleMount block (standalone)](../mounting-block/index.md) | ✅ Published |

Community contributions are welcome before these are officially published.

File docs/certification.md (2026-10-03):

---
description: OpenPoleMount is certified open source hardware by the Open Source Hardware Association (OSHWA) — four certifications, US002834, US002862, US002863 and US002864.
---

# Certified Open Source Hardware

<div style="font-size:1.15rem;line-height:1.55;margin:0.5rem 0 1.5rem;">
OpenPoleMount is <strong>certified open source hardware</strong> by the
<a href="https://certification.oshwa.org/">Open Source Hardware Association (OSHWA)</a>.
Every cradle in the line — the v3 cradle, the v2 universal holder and the v1 accessory
box — is listed in OSHWA's public certification directory, each with its own ID.
</div>

<style>
  .opm-certs { display:grid; grid-template-columns:repeat(auto-fit,minmax(220px,1fr)); gap:1.25rem; margin:1.5rem 0 2rem; }
  .opm-cert { border:1px solid var(--md-default-fg-color--lightest); border-radius:12px; padding:1rem; text-align:center; }
  .opm-cert__tile { display:block; background:#fff; border-radius:10px; padding:14px; margin-bottom:0.75rem; }
  .opm-cert__tile img { display:block; width:100%; max-width:170px; height:auto; margin:0 auto; }
  .opm-cert__name { font-weight:700; margin:0.25rem 0; }
  .opm-cert__meta { font-size:0.8rem; color:var(--md-default-fg-color--light); margin:0 0 0.5rem; }
</style>

<div class="opm-certs">
  <div class="opm-cert">
    <a class="opm-cert__tile" href="https://certification.oshwa.org/us002864.html" title="OSHWA certificate US002864">
      OSHW certification mark US002864</a>
    <p class="opm-cert__name"><a href="../iv-pole-v3/">IV Pole Cradle v3</a></p>
    <p class="opm-cert__meta">US002864 · certified Oct 3, 2026<br>the current, recommended cradle</p>
  </div>
  <div class="opm-cert">
    <a class="opm-cert__tile" href="https://certification.oshwa.org/us002863.html" title="OSHWA certificate US002863">
      OSHW certification mark US002863</a>
    <p class="opm-cert__name"><a href="../iv-pole-v2/">IV Pole Cradle v2 (Universal Holder)</a></p>
    <p class="opm-cert__meta">US002863 · certified Oct 3, 2026</p>
  </div>
  <div class="opm-cert">
    <a class="opm-cert__tile" href="https://certification.oshwa.org/us002862.html" title="OSHWA certificate US002862">
      OSHW certification mark US002862</a>
    <p class="opm-cert__name"><a href="../print-settings/">IV Pole Accessory Box (v1)</a></p>
    <p class="opm-cert__meta">US002862 · certified Oct 3, 2026</p>
  </div>
  <div class="opm-cert">
    <a class="opm-cert__tile" href="https://certification.oshwa.org/us002834.html" title="OSHWA certificate US002834">
      OSHW certification mark US002834</a>
    <p class="opm-cert__name"><a href="../iv-pole-v2/">IV Pole Cradle</a></p>
    <p class="opm-cert__meta">US002834 · certified Jul 10, 2026<br>the project's first certification</p>
  </div>
</div>

Click any mark to open its certificate in OSHWA's directory.

## What the certification means

OSHWA certification confirms that a project meets the
[Open Source Hardware Definition](https://www.oshwa.org/definition/): the design files,
documentation and bill of materials are public, and the licenses let anyone study,
make, modify and share the hardware. For OpenPoleMount that means:

- **Hardware:** [CERN-OHL-W-2.0](license.md) — print it, change it, sell it; improvements to the design itself stay open.
- **Documentation:** [CC-BY-SA-4.0](license.md).
- **Source files:** the native Blender `.blend` sources and print-ready STLs are in the
  [GitHub repository](https://github.com/GoR-XarraY/openpolemount) and on the
  [v3.0.0 release](https://github.com/GoR-XarraY/openpolemount/releases/tag/v3.0.0).

!!! warning "Open source — not a medical or safety certification"
    OSHWA certifies that the design is **open**. It does not test strength or safety,
    and it is not a medical certification. OpenPoleMount remains general-purpose
    mounting hardware, not a medical device, and is not FDA-cleared.
    See [Safety & Disclaimer](safety.md).

## Plain-text mark

Where an image can't be used, OSHWA's plain-text form is:

```
[OSHW] US002864 | Certified open source hardware | oshwa.org/cert
```

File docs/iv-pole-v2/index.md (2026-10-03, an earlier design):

---
title: IV Pole Mount v2 — Universal Device Holder
description: Open source 3D-printable universal equipment holder for home IV poles — a general-purpose pocket that may fit various small devices
image: images/iv-pole-v2/v2-og-image.jpg
---

# IV Pole Cradle v2 — Universal Device Holder

<div style="display:flex;align-items:center;gap:1rem;padding:0.9rem 1rem;margin:1rem 0 1.5rem;border-radius:10px;border:1px solid var(--md-default-fg-color--lightest);">
  <a href="https://certification.oshwa.org/us002863.html" style="flex:none;display:block;background:#fff;border-radius:8px;padding:8px;" title="OSHWA certificate US002863">
    OSHW certification mark US002863
  </a>
  <div><strong>Certified open source hardware</strong> — the v2 universal holder is OSHWA certificate
  <a href="https://certification.oshwa.org/us002863.html">US002863</a>. (Its first listing, July 2026, is <a href="https://certification.oshwa.org/us002834.html">US002834</a>.)
  <a href="../../certification/">About the certifications →</a></div>
</div>

**A general-purpose pocket for a home IV pole. Its more open shape isn't fitted to
one specific device, so it may hold several different small devices — not just one
model.**

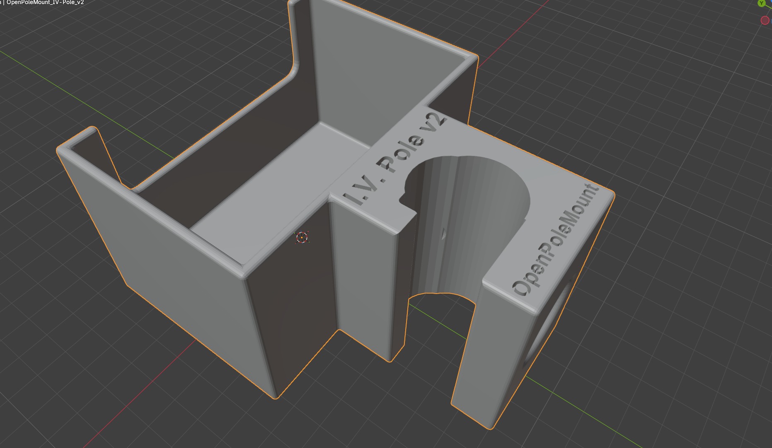
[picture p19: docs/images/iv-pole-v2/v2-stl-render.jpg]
IV Pole Cradle v2 — Blender model, equipment pocket at left, U-shaped pole channel at right

*IV Pole Cradle v2 in Blender — U-shaped pole channel and thumbscrew boss at right, general-purpose pocket at left, embossed "I.V. Pole v2" / "OpenPoleMount" labels.*

---

!!! success "Need a tighter, more form-fitting pocket? Print v3 instead"
    **[v3](../iv-pole-v3/index.md) is the recommended, more form-fitting cradle** —
    it's a smaller redesign built from feedback on this v2 pocket.

    **v2 is still a good print** — it's now documented here as a **universal device
    holder**: its more open pocket may fit several small devices of similar size,
    but **we do not yet have a compatibility list**. If you print v2 and it
    holds your device well (or doesn't), please
    [open an issue and tell us](https://github.com/GoR-XarraY/openpolemount/issues) —
    fit reports from the community are how this list gets built.

    The original [**v1**](../print-settings.md) is **not functional as a device cradle** —
    the device's buttons and screen are not accessible when it's seated in it. v1 is
    best repurposed as an accessory box that mounts on the pole below the device.

## Printing Footage

<div style="display:flex;justify-content:center;margin:1.5rem 0;">
  <iframe width="315" height="560"
    src="https://www.youtube.com/embed/z05xgJhH_BQ"
    title="OpenPoleMount IV Pole V2 — printing the first one"
    frameborder="0"
    allow="accelerometer; autoplay; clipboard-write; encrypted-media; gyroscope; picture-in-picture"
    allowfullscreen>
  </iframe>
</div>

## Installed Photos

These photos show v2 holding a Curlin CMS6000 — the pairing it was originally
photographed with, before v3's more form-fitting pocket was designed. They
illustrate the pocket's general size and shape; they are not a claim that v2 is
the recommended holder for this or any specific device.

<div style="display:grid;grid-template-columns:1fr 1fr;gap:1rem;margin:1.5rem 0;">
  <div>
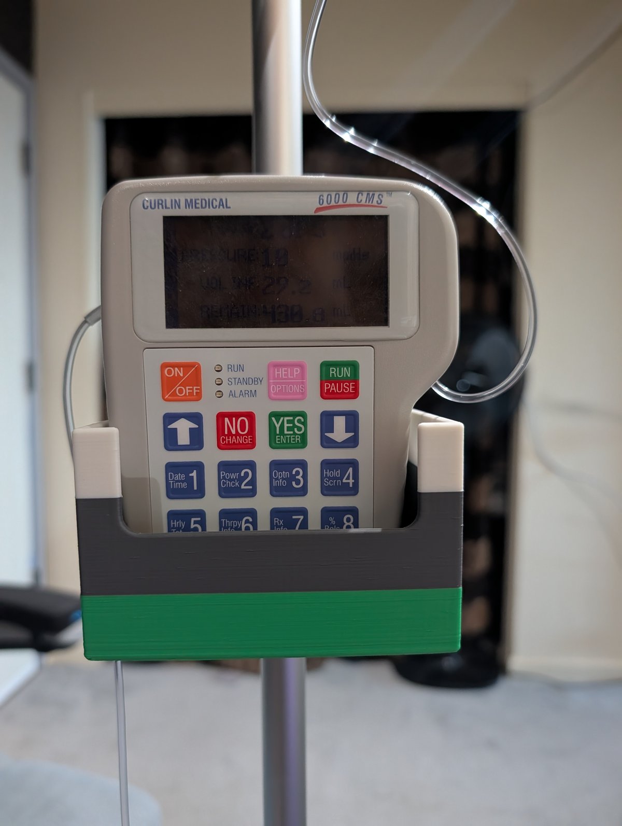
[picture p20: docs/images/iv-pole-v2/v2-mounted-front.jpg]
Device in V2 cradle — front view
    
    <p style="font-size:0.85em;color:#666;margin-top:0.4rem;">Front — device fully seated, keypad accessible</p>
  </div>
  <div>
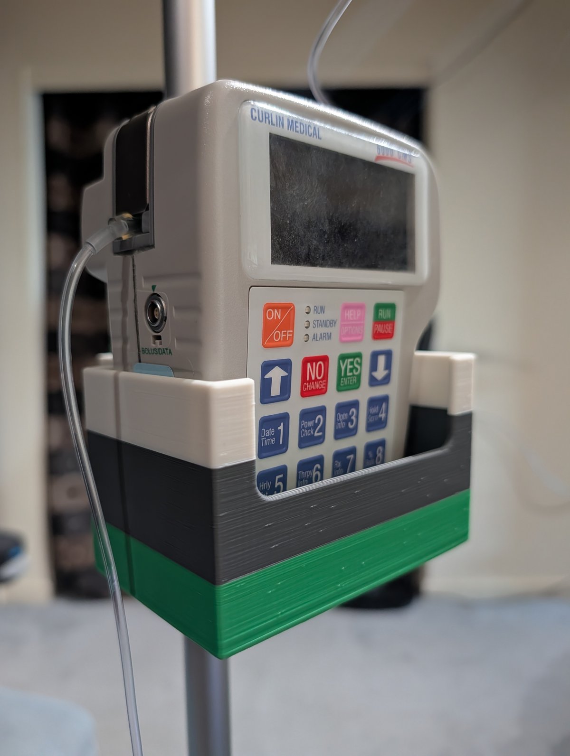
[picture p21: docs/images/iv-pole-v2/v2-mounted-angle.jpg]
V2 mount — 3/4 angle view
    
    <p style="font-size:0.85em;color:#666;margin-top:0.4rem;">3/4 angle — device in cradle, tubing routed</p>
  </div>
  <div>
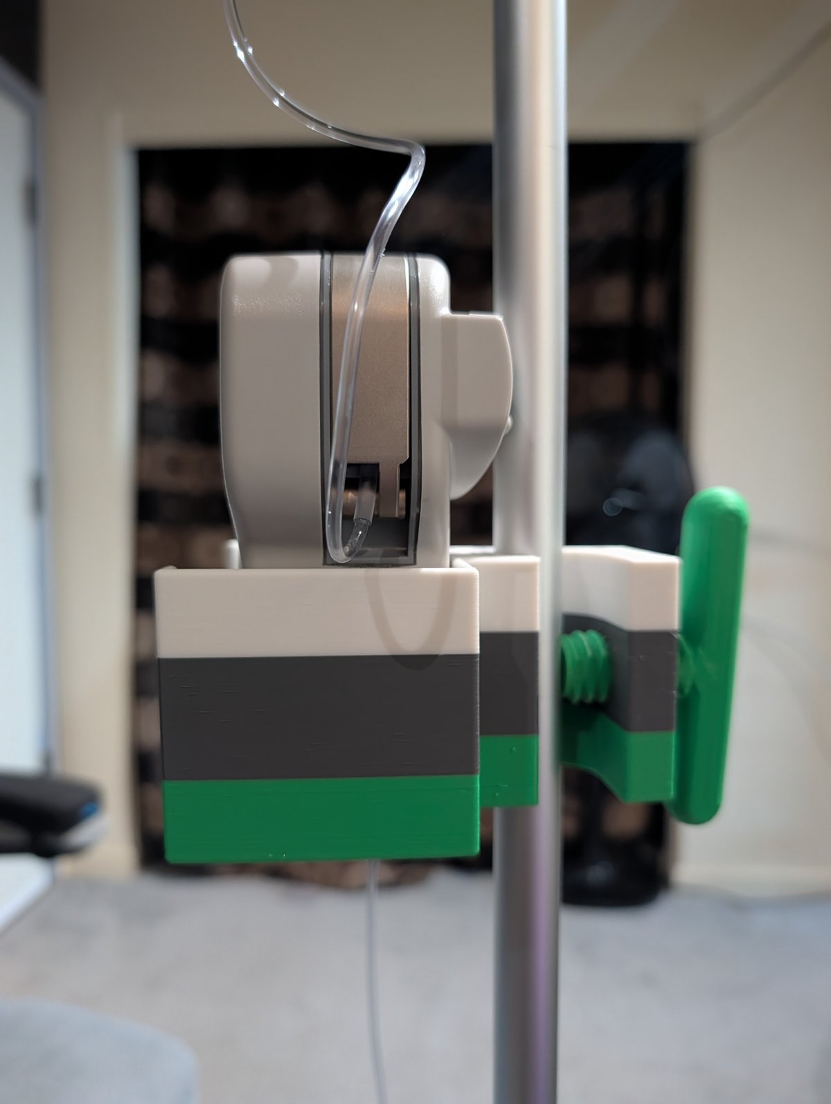
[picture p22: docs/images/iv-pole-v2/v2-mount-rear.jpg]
V2 mount — rear with thumbscrew
    
    <p style="font-size:0.85em;color:#666;margin-top:0.4rem;">Rear — green T-handle thumbscrew on pole</p>
  </div>
  <div>
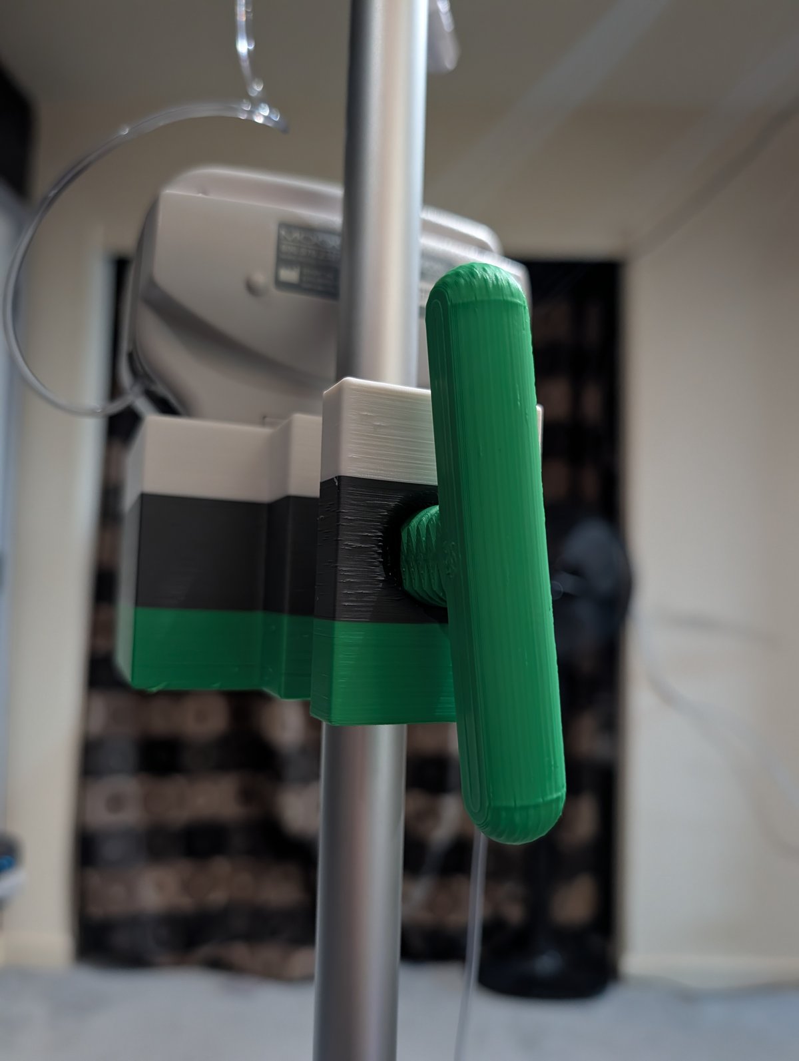
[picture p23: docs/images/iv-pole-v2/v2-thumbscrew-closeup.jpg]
T-handle thumbscrew close-up
    
    <p style="font-size:0.85em;color:#666;margin-top:0.4rem;">Thumbscrew detail — hand-tighten only</p>
  </div>
</div>

### Example Fit — Curlin CMS6000 (Original Photos)

*User-reported example fit — not a manufacturer claim, not verified for any medical use.*

<div style="display:grid;grid-template-columns:1fr 1fr;gap:1rem;margin:1.5rem 0;">
  <div>
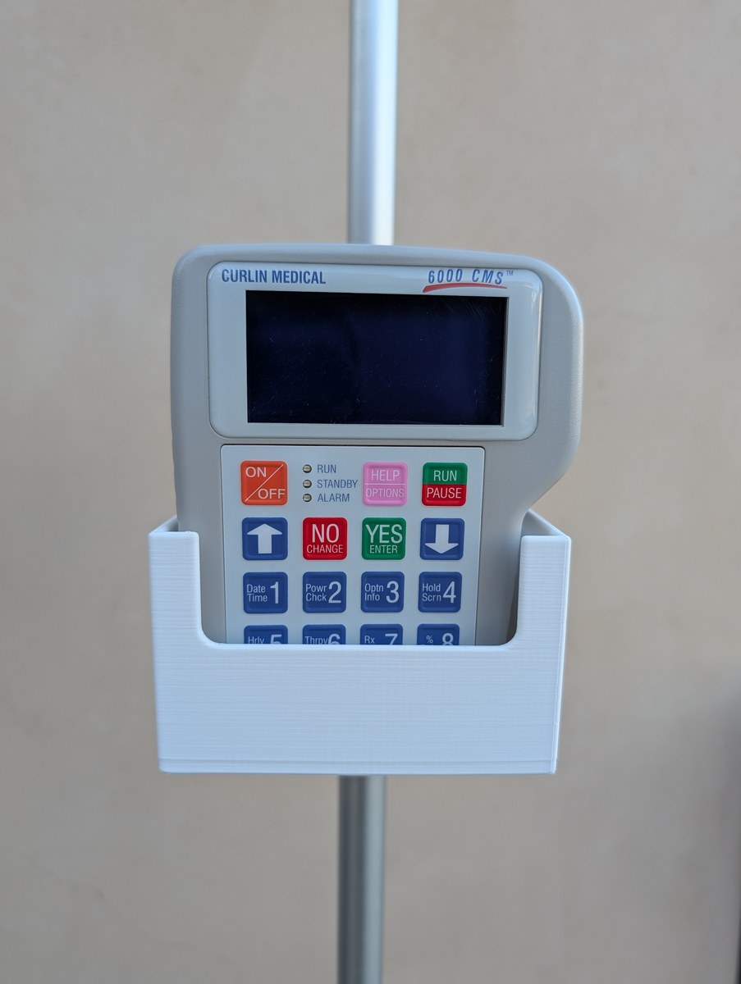
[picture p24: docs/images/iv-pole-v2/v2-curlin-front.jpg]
Curlin CMS6000 front in V2 cradle
    
    <p style="font-size:0.85em;color:#666;margin-top:0.4rem;">Curlin CMS6000 — front view, device fully seated</p>
  </div>
  <div>
    <a href="../images/iv-pole-v2/v2-curlin-straight.jpg">Curlin CMS6000 straight-on in V2 cradle</a>
    <p style="font-size:0.85em;color:#666;margin-top:0.4rem;">Curlin CMS6000 — straight-on, keypad fully visible</p>
  </div>
  <div>
    <a href="../images/iv-pole-v2/v2-curlin-side.jpg">Curlin CMS6000 in V2 cradle — side view</a>
    <p style="font-size:0.85em;color:#666;margin-top:0.4rem;">Side — cradle body and pole channel visible</p>
  </div>
  <div>
    <a href="../images/iv-pole-v2/v2-curlin-top.jpg">Curlin CMS6000 in V2 cradle — overhead angle</a>
    <p style="font-size:0.85em;color:#666;margin-top:0.4rem;">Overhead angle — device seated in cradle pocket</p>
  </div>
  <div>
    <a href="../images/iv-pole-v2/v2-curlin-back-left.jpg">Curlin CMS6000 in V2 cradle — back-left view</a>
    <p style="font-size:0.85em;color:#666;margin-top:0.4rem;">Back-left — rear of device, thumbscrew engaged</p>
  </div>
  <div>
    <a href="../images/iv-pole-v2/v2-curlin-back-right.jpg">Curlin CMS6000 in V2 cradle — back-right view</a>
    <p style="font-size:0.85em;color:#666;margin-top:0.4rem;">Back-right — device seated, pole channel at right</p>
  </div>
  <div>
    <a href="../images/iv-pole-v2/v2-curlin-top2.jpg">Curlin CMS6000 in V2 cradle — top-down</a>
    <p style="font-size:0.85em;color:#666;margin-top:0.4rem;">Top-down — device fully seated in cradle pocket</p>
  </div>
</div>

### Cradle Detail — Empty

<div style="display:grid;grid-template-columns:1fr 1fr;gap:1rem;margin:1.5rem 0;">
  <div>
    <a href="../images/iv-pole-v2/v2-empty-front.jpg">V2 cradle empty — front view</a>
    <p style="font-size:0.85em;color:#666;margin-top:0.4rem;">Empty cradle — open front shows the pocket shape</p>
  </div>
  <div>
    <a href="../images/iv-pole-v2/v2-empty-side.jpg">V2 cradle empty — side with thumbscrew</a>
    <p style="font-size:0.85em;color:#666;margin-top:0.4rem;">Side — thumbscrew threaded through pole channel</p>
  </div>
  <div>
    <a href="../images/iv-pole-v2/v2-empty-top.jpg">V2 cradle empty — top-down</a>
    <p style="font-size:0.85em;color:#666;margin-top:0.4rem;">Top-down — "I.V. Pole v2" label embossed on body</p>
  </div>
  <div>
    <a href="../images/iv-pole-v2/v2-empty-rear.jpg">V2 cradle empty — rear view</a>
    <p style="font-size:0.85em;color:#666;margin-top:0.4rem;">Rear — U-shaped pole channel and cradle walls</p>
  </div>
  <div>
    <a href="../images/iv-pole-v2/v2-channel-detail.jpg">V2 pole channel and thumbscrew close-up</a>
    <p style="font-size:0.85em;color:#666;margin-top:0.4rem;">Channel detail — thumbscrew seats flush against pole</p>
  </div>
</div>

---

<div style="padding:1.75rem;background:var(--md-code-bg-color);border-radius:8px;border-left:5px solid var(--md-primary-fg-color);margin:2rem 0;">
  <div style="font-size:1.2rem;font-weight:800;margin-bottom:0.5rem;">🖨️ Print it yourself — free & open source</div>
  <div style="font-size:0.9rem;color:var(--md-default-fg-color--light);margin-bottom:1.25rem;">Download the v2 STL files and print on any FDM printer. This is the whole point of the project.</div>
  <a href="../iv-pole-v2/print-settings/" style="display:inline-block;padding:0.55rem 1.4rem;background:var(--md-primary-fg-color);color:white;border-radius:4px;text-decoration:none;font-size:0.95rem;font-weight:700;">Print Guide →</a>
</div>

<div style="font-size:0.85rem;color:var(--md-default-fg-color--light);margin:1rem 0;">
  No printer or maker nearby? You can have v2 printed on demand and shipped via
  Slant 3D / Teleport — a fallback, not the goal. <a href="../order/">No printer? Order one →</a>
</div>

## Next Steps

1. **[Print Guide →](print-settings.md)** — settings, orientation, checklist
2. **[Assembly →](assembly.md)** — step-by-step with photos
3. **[Safety & Disclaimer →](../safety.md)** — read before use
4. **[Need a tighter, more form-fitting cradle? See v3 →](../iv-pole-v3/index.md)**

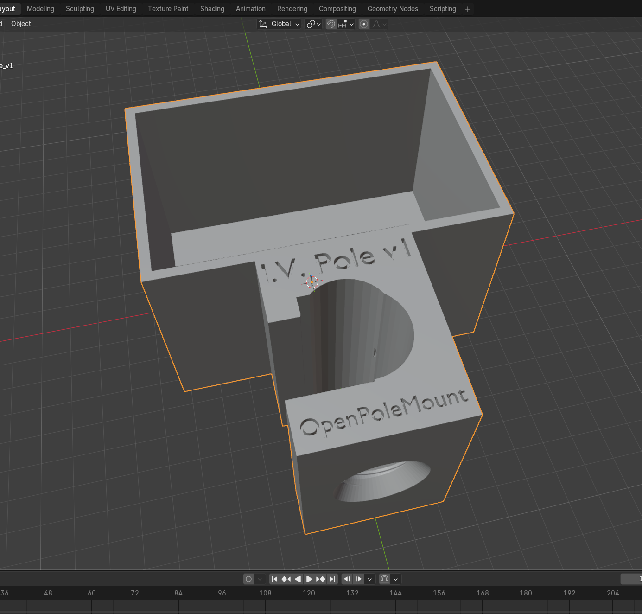
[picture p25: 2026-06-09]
docs/images/hero.png

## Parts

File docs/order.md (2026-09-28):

---
title: No Printer? Order One
description: If you can't 3D print the OpenPoleMount v3 IV pole cradle yourself, you can have it printed in PETG on demand via Slant 3D (Teleport) and shipped to you.
---

# No Printer? Order One

!!! note "Printing it yourself is the goal — this page is the fallback"
    OpenPoleMount is an open-source hardware project, **not a business**.
    The intended path is that you (or a maker friend) **print a cradle yourself
    for free** — see the [v3 Print Guide](iv-pole-v3/print-settings.md) (form-fitted
    pocket) or the [v2 Print Guide](iv-pole-v2/print-settings.md)
    (universal holder). This page exists so people **without access to a
    printer** aren't left out.

If you don't have a 3D printer and can't find a maker nearby, you can have the
**IV Pole Cradle v3** printed on demand and shipped to you.

## How it's printed

Orders are fulfilled through **Teleport**, the print-on-demand service from
**[Slant 3D](https://www.slant3d.com/)**. They print the exact same open-source
files published on this site — there's no special or "official" version. Parts are
printed on Slant 3D's standard Teleport profile below, which meets the
[recommended minimums](iv-pole-v3/print-settings.md) documented here.

!!! warning "This is a reference design, not a medical device"
    The printed parts you receive are the same open-source design published on this site.
    You are responsible for verifying mechanical integrity before use.
    [Read the full safety disclaimer →](safety.md)

!!! info "PETG has not been strength-tested by this project yet"
    The v3 order is printed in **PETG**. The project's load and over-tightening
    tests so far were done on **PLA** prints (see [Testing](testing.md)). Inspect
    your parts, hand-tighten only, and verify the mount holds before relying on it.

---

## v3 cradle (PETG) — $30 + shipping

| Item | Spec |
|---|---|
| Cradle body | Current v3 design, textured finish |
| Thumbscrew | `thumbscrew_v14_flat_Thandle.stl` — T-handle grip |
| Material | PETG — Black, White, or Carbon Fiber (choose below) |
| Layer height | 0.2 mm |
| Walls (incl. top/bottom) | 1 mm |
| Infill | 25% grid |
| Tools needed | None — hand-tighten only |

<div style="display:flex;justify-content:center;margin:2rem 0;">
  <iframe title="OpenPoleMount Universal Equipment Cradle v3 - PETG" width="500" height="1900"
    src="https://teleportpod.com/portal/8d65528f-d89b-4859-a95e-49c19c678b32?item=8299"
    frameborder="0" style="border-radius:8px;max-width:100%;">
  </iframe>
</div>

Once your parts arrive, follow the [v3 Assembly Guide →](iv-pole-v3/assembly.md).
No tools required — the cradle mounts to your IV pole by hand in under a minute.

---

## v2 universal holder (PLA) — $25 + shipping

Prefer the larger, universal v2 holder? It's still available in PLA (Matte Blue),
printed on the same Teleport profile.
[v2 Assembly Guide →](iv-pole-v2/assembly.md)

<div style="display:flex;justify-content:center;margin:2rem 0;">
  <iframe title="OpenPoleMount Universal Equipment Cradle v2 - PLA" width="500" height="1500"
    src="https://teleportpod.com/portal/32850c5d-072b-4768-982d-532d3b36d325?item=5407"
    frameborder="0" style="border-radius:8px;max-width:100%;">
  </iframe>
</div>

---

## Questions?

[Open an issue on GitHub](https://github.com/GoR-XarraY/openpolemount/issues) — include
your order details and we'll help.

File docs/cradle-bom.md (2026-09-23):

---
title: Cradle Bill of Materials (v1 / v2 / v3)
description: Bill of materials for the OpenPoleMount IV-pole cradles — fully 3D-printed, with measured filament use for each version.
---

# Cradle Bill of Materials — v1, v2, v3

Every OpenPoleMount cradle is **fully 3D-printed**: a cradle body plus the shared
printed T-handle thumbscrew. There are no proprietary or purchased parts — the only
consumable is filament. Each cradle is built on the
[OpenPoleMount mounting block](mounting-block/index.md) and clamps to a standard
IV pole the same way.

!!! info "General-purpose hardware"
    These are general-purpose mounting hardware, not medical devices. See the
    [Safety & Disclaimer](safety.md).

## Shared part — thumbscrew

| Part | File | Qty | Filament (measured) |
|---|---|---|---|
| T-handle Thumbscrew | [`thumbscrew_v14_flat_Thandle.stl`](https://github.com/GoR-XarraY/openpolemount/raw/main/stl/thumbscrew_v14_flat_Thandle.stl) | 1 | ~14 g (~11 cm³) |

All three cradles use this same thumbscrew.

## v3 — form-fitting cradle (current)

| Item | Value |
|---|---|
| Cradle file | [`OpenPoleMount_IV-Pole_v3.stl`](https://github.com/GoR-XarraY/openpolemount/raw/main/stl/OpenPoleMount_IV-Pole_v3.stl) |
| Printed size (L × W × H) | 125 × 100 × 66 mm |
| Filament, cradle body | **~109 g** PLA (~88 cm³) · **~91 g** PETG (~74 cm³) — figures come from different slicer profiles, not a material property; your slicer's estimate governs |
| + thumbscrew | ~14 g |
| Print time | ~3 h 10 m (PLA, 0.2 mm) |

## v2 — universal holder (available now)

| Item | Value |
|---|---|
| Cradle file | [`OpenPoleMount_IV-Pole_v2.stl`](https://github.com/GoR-XarraY/openpolemount/raw/main/stl/OpenPoleMount_IV-Pole_v2.stl) |
| Printed size (L × W × H) | 126 × 105 × 65 mm |
| Filament, cradle body | **~197 g** PLA (~159 cm³) |
| + thumbscrew | ~14 g |
| Print time | ~6–8 h (PLA, 0.2 mm) |

## v1 — accessory box (legacy)

| Item | Value |
|---|---|
| Body file | [`OpenPoleMount_IV-Pole_v1.stl`](https://github.com/GoR-XarraY/openpolemount/raw/main/stl/OpenPoleMount_IV-Pole_v1.stl) |
| Printed size (L × W × H) | 126 × 105 × 65 mm |
| Filament, body | **~206 g** PLA (~166 cm³) |
| + thumbscrew | ~14 g |
| Print time | ~6.5 h (PLA, 0.2 mm) |

## Consumable — filament

| Material | Spec | Notes |
|---|---|---|
| PLA (validated) or PETG | 1.75 mm, any reputable brand | No specific brand required. PETG suits higher-stress or warmer environments but is [not yet strength-tested](iv-pole-v3/print-settings.md) for these designs. Where PLA and PETG filament figures differ on this page, they were measured with different slicer profiles — same STL geometry. |

Filament figures above are measured from real single-unit slices at the recommended
0.2 mm settings; your slicer reports the exact figure for your setup.

## Print specification (safety-critical)

All cradles print at or above the shared recommended minimums:

| Parameter | Recommended minimum |
|---|---|
| Material | PLA (or PETG) |
| Layer height | 0.2 mm |
| Walls | ≥1 mm |
| Top/bottom | ≥1 mm |
| Infill | ≥25 %, any non-concentric pattern (grid OK — **not** concentric) |
| Supports | None required |
| Orientation | Cradle: pole channel vertical (layers perpendicular to clamp load). Thumbscrew: flat, handle face down. |

Full details: [v3 Print Guide](iv-pole-v3/print-settings.md) ·
[v2 Print Guide](iv-pole-v2/print-settings.md) · [About v1](print-settings.md).

## Source files

Native editable source CAD (Blender `.blend`) for every cradle lives in the
repository's [`source/`](https://github.com/GoR-XarraY/openpolemount/tree/main/source)
folder; the print-ready STL meshes are under
[`stl/`](https://github.com/GoR-XarraY/openpolemount/tree/main/stl). Both are
available for remixing under the hardware license (CERN-OHL-W-2.0).

---

*Fully 3D-printed — no BOM entries for purchased hardware. Provided for informational
purposes only; verify every printed part before use.*

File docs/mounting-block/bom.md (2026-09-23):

---
title: Mounting Block — Bill of Materials
description: Bill of materials for the OpenPoleMount mounting block — a fully 3D-printed pole clamp with no proprietary or non-printed parts.
---

# Mounting Block — Bill of Materials (BOM)

The OpenPoleMount mounting block is **fully 3D-printed**. There are no proprietary,
purchased, or non-printed components — the complete assembly is two printed parts
plus filament. This keeps the whole part openly reproducible by anyone with a
printer.

!!! info "General-purpose hardware"
    This is general-purpose mounting hardware, not a medical device. See the
    [Safety & Disclaimer](../safety.md) page.

## Printed parts

| # | Part | File | Qty | Manufacturer / Part No. |
|---|---|---|---|---|
| 1 | Pole Mounting Block | [`OpenPoleMount_Pole_Mounting_Block_V1.stl`](https://github.com/GoR-XarraY/openpolemount/raw/main/stl/OpenPoleMount_Pole_Mounting_Block_V1.stl) | 1 | Self-printed (open design — no proprietary part) |
| 2 | T-handle Thumbscrew | [`OpenPoleMount_Pole_Mounting_Block_ThandleThumbscrew-V1.stl`](https://github.com/GoR-XarraY/openpolemount/raw/main/stl/OpenPoleMount_Pole_Mounting_Block_ThandleThumbscrew-V1.stl) | 1 | Self-printed (open design — no proprietary part) |

## Consumable — filament

| Material | Spec | Notes |
|---|---|---|
| **PLA** (validated) or **PETG** (stronger, lighter, more heat/creep tolerant) | 1.75 mm filament, any reputable brand | No specific brand required. Destruction testing was performed in standard PLA; PETG is recommended for higher-stress or warmer environments. |

**Measured filament use** (single unit, sliced at 0.2 mm layer height on the
recommended profile):

| Part | Filament (measured) | Volume |
|---|---|---|
| T-handle Thumbscrew | **~14 g** | ~11 cm³ |
| Full v3 cradle (block + pocket) — *reference* | **~109 g** PLA | ~88 cm³ |

PLA and PETG use near-identical filament *volume*; mass differs only slightly with
density (PLA ~1.24, PETG ~1.27 g/cm³).

!!! note "Bare-block-only figure pending"
    The full v3 cradle above is measured from a real slice (single unit, ~3 h 10 m
    print). The **bare mounting block on its own** has not been sliced separately —
    as a subset of the cradle it uses less than the full-cradle figure. *(Pending a
    block-only slice for an exact number; your slicer's estimate is authoritative.)*

## Print specification (safety-critical)

The block is a load-bearing part; wall count and infill are safety-critical. Print
both parts at or above the shared recommended minimums:

| Parameter | Recommended minimum |
|---|---|
| Material | PLA (or PETG) |
| Layer height | 0.2 mm |
| Walls | ≥1 mm |
| Top/bottom | ≥1 mm |
| Infill | ≥25 %, any non-concentric pattern (grid OK — **not** concentric) |
| Supports | None required |
| Orientation | Block: pole channel vertical (layers perpendicular to clamp load). Thumbscrew: flat, handle face down. |

Full details and rationale: **[Print Guide](../iv-pole-v3/print-settings.md)**.

## Dimensions

Measured directly from the STL geometry:

| Part | Bounding size (X × Y × Z) |
|---|---|
| Pole Mounting Block v1 | 48.0 × 57.9 × 59.5 mm |
| T-handle Thumbscrew v1 | 102.0 × 53.0 × 16.0 mm |

## Source files

Native editable source CAD (Blender `.blend`) for the block lives in the
repository's [`source/`](https://github.com/GoR-XarraY/openpolemount/tree/main/source)
folder; the print-ready STL meshes are under
[`stl/`](https://github.com/GoR-XarraY/openpolemount/tree/main/stl). Both are
available for remixing under the hardware license (CERN-OHL-W-2.0).

---

*Fully 3D-printed — no BOM entries for purchased hardware. This documentation is
provided for informational purposes only; verify every printed part before use.*

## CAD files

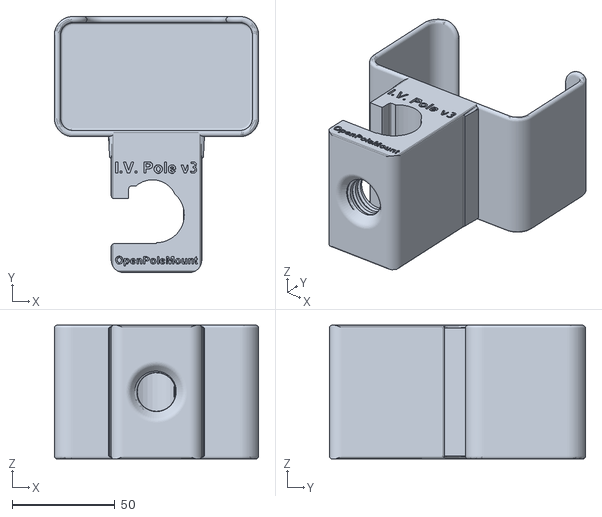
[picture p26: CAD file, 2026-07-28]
stl/OpenPoleMount_IV-Pole_v3.stl
99.3 x 124.4 x 65.0

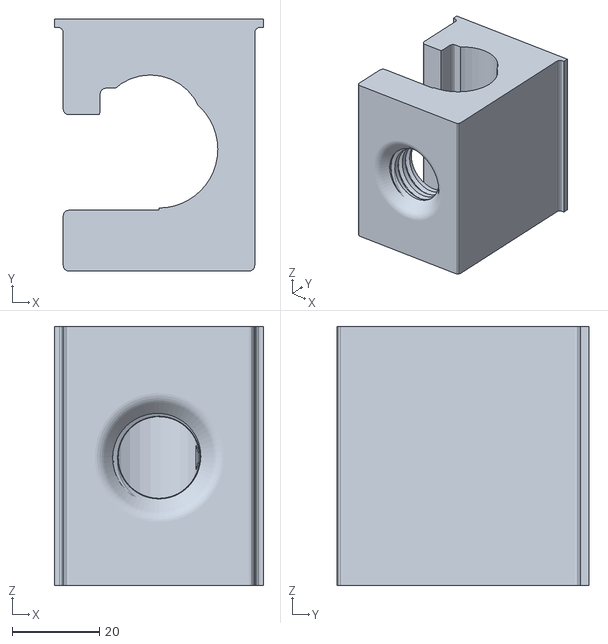
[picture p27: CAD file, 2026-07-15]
stl/OpenPoleMount_Pole_Mounting_Block_V1.stl
48.0 x 57.9 x 59.5

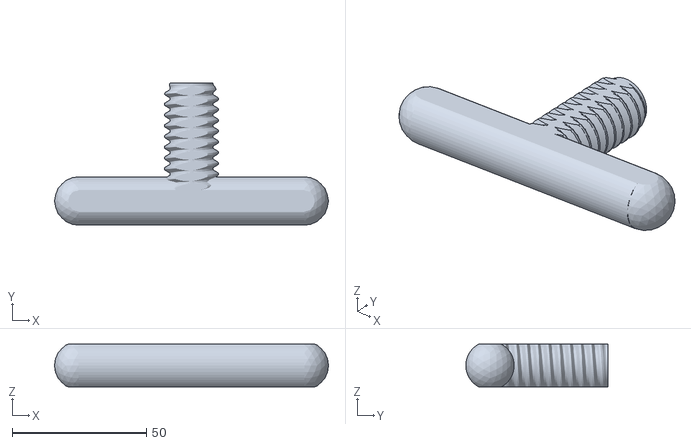
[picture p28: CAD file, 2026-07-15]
stl/OpenPoleMount_Pole_Mounting_Block_ThandleThumbscrew-V1.stl
102.0 x 53.0 x 16.0

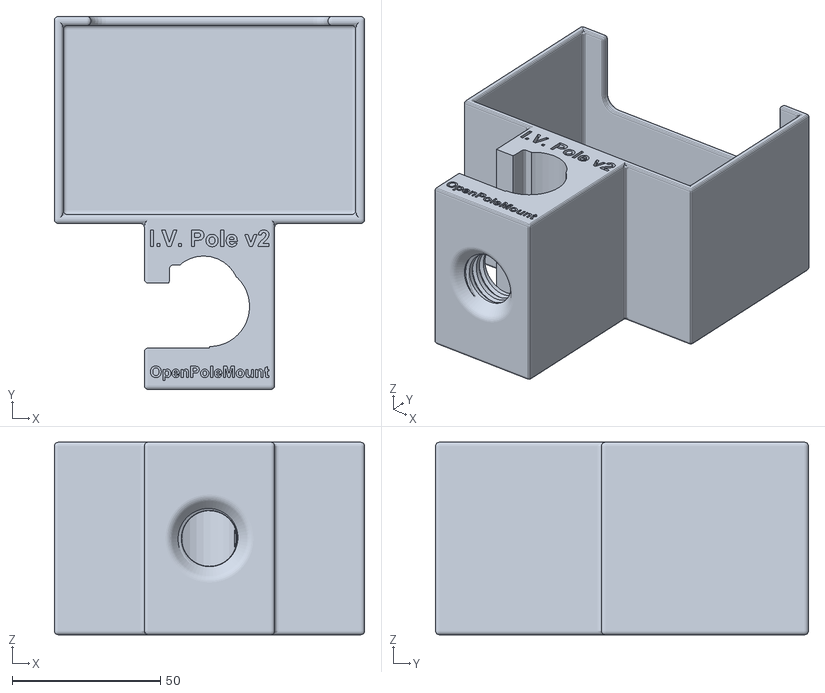
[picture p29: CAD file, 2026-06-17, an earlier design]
stl/OpenPoleMount_IV-Pole_v2.stl
104.7 x 125.8 x 65.0

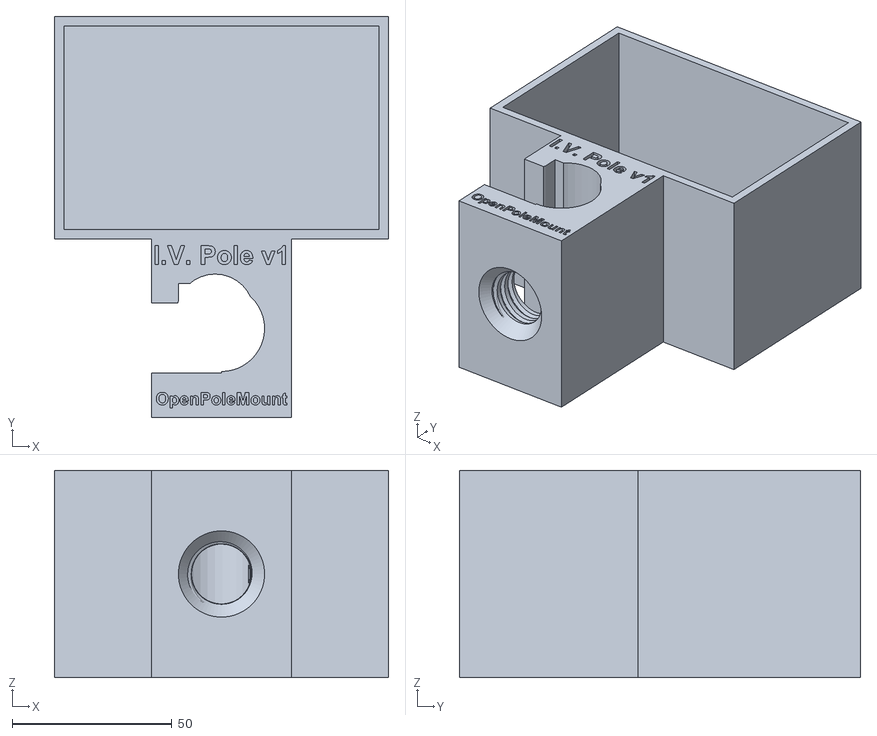
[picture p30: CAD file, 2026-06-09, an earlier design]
stl/OpenPoleMount_IV-Pole_v1.stl
104.7 x 125.8 x 65.0

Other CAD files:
stl/thumbscrew_v14_flat_Thandle.stl
source/OpenPoleMount_IV-Pole_v1.blend
source/OpenPoleMount_IV-Pole_v2.blend
source/OpenPoleMount_IV-Pole_v3.blend
source/OpenPoleMount_Pole_Mounting_Block_V1.blend
source/OpenPoleMount_Pole_THandle_Thumbscrew.blend

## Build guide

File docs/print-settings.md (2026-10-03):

# v1 — Accessory Box: About & Printing

<div style="display:flex;align-items:center;gap:1rem;padding:0.9rem 1rem;margin:1rem 0 1.5rem;border-radius:10px;border:1px solid var(--md-default-fg-color--lightest);">
  <a href="https://certification.oshwa.org/us002862.html" style="flex:none;display:block;background:#fff;border-radius:8px;padding:8px;" title="OSHWA certificate US002862">
    OSHW certification mark US002862
  </a>
  <div><strong>Certified open source hardware</strong> — the v1 accessory box is OSHWA certificate
  <a href="https://certification.oshwa.org/us002862.html">US002862</a>.
  <a href="../certification/">About the certifications →</a></div>
</div>

!!! info "Use v2 to hold equipment. Use v1 as an accessory box."
    **v1 is the original print, and it's not functional as an equipment cradle** — the
    equipment's buttons and screen are not accessible when it is seated in v1. Use the current
    [**IV Pole Cradle v2**](iv-pole-v2/index.md). For a general-purpose pocket,
    **print v2**.

    v1 is still useful: it's best repurposed as an **accessory box that mounts on the
    pole below the cradle** — for alcohol wipes, spare caps, tubing, or other small supplies.
    The print settings, thumbscrew, and OpenPoleMount block are the same as v2, so it
    still clamps to any standard home IV pole.

The rest of this page is the original v1 print and assembly reference.

!!! danger "Safety Note — Read First"
    Anything you hang on an IV pole can fall. Print quality affects how well the box
    holds together and stays on the pole. The settings below are **minimums** — you are
    responsible for verifying mechanical integrity before use. See
    [Safety & Disclaimer](safety.md).

## Required Files

Download from [GitHub Releases](https://github.com/GoR-XarraY/openpolemount/releases/latest):

| File | Purpose | Quantity |
|---|---|---|
| `OpenPoleMount_IV-Pole_v1.stl` | Accessory box | 1 |
| `thumbscrew_v14_flat_Thandle.stl` | Thumbscrew for pole attachment | 1 |

!!! success "Tested to Destruction (2026-06-09)"
    An under-spec print (4-layer walls, 1 mm top/bottom, 15% non-structural infill, standard PLA)
    **never failed under load**. Failure only occurred under deliberate extreme over-tightening —
    the thumbscrew punched through the side wall, a safe and predictable failure mode.
    The recommended settings below are conservative relative to this tested limit.
    [See full testing results →](testing.md)

## Material

**PLA** is the tested and validated material for this design. Settings on this page
are based on PLA testing. Other materials (PETG, ASA, ABS) have not yet been tested —
if you print in another material, please share your results by
[opening an issue](https://github.com/GoR-XarraY/openpolemount/issues).

| Material | Status |
|---|---|
| **PLA** | ✅ Tested — use the settings below |
| PETG / ASA / ABS | ⚠️ Not yet tested — proceed at your own risk |
| TPU / Flexible | ❌ Not suitable — cannot support structural load |

## Recommended Print Settings (PLA, tested)

| Setting | Box | Thumbscrew |
|---|---|---|
| Layer height | 0.2 mm | 0.2 mm |
| **Wall count** | **1 mm minimum (≈2–3 perimeters at 0.4 mm nozzle)** | **1 mm minimum** |
| **Top/bottom thickness** | **1 mm minimum** | **1 mm minimum** |
| **Infill** | **25% minimum — any non-concentric pattern (grid, gyroid, cubic, etc.)** | **25% minimum** |
| Infill pattern | Grid, gyroid, cubic, or similar — **not** concentric | same |
| Supports | None needed | Optional — single layer keeps part in place; brim works too |
| Print speed | 40–60 mm/s | 40–60 mm/s |

!!! danger "Wall and Infill Minimums Are Safety-Critical"
    Testing has shown that the mount **can crack if over-tightened** when walls
    or infill are below these minimums. The 1 mm wall + 1 mm top/bottom + 25%
    non-concentric infill combination is the recommended minimum.

    **Do not use concentric infill** — it does not provide
    the same resistance to the stress concentration from the thumbscrew.

## Part Orientation

**Box:** Print with the pole channel vertical (mounting hole facing up). This
orients layer lines perpendicular to the primary load direction, maximizing
pull-out and shear strength.

**Thumbscrew:** Print flat with the T-handle face down. No supports needed.

## Support Settings

Neither part requires supports. Supports are optional on both:

- **Box:** supports are not required. If you use them, place under the box cavity. Tree or Normal both work; 45° threshold; 2–3 interface layers for clean removal.
- **Thumbscrew:** supports are not required. If enabled, the slicer typically places a single layer under the part — this helps hold it in place during printing. A brim works equally well for this purpose.

## Post-Processing

After printing:

1. Remove all supports carefully — use flush cutters, not a knife
2. Clean the thumbscrew threads with a brush if needed
3. Test-fit thumbscrew in the threaded hole — should turn smoothly by hand
4. Verify the pole channel diameter matches your IV pole
5. Check the box cavity is clean and free of stringing so contents don't snag

## Verification Before Use

Run through this checklist before mounting the box:

- [ ] No visible layer delamination (check by pressing firmly — should not crack or flex excessively)
- [ ] No significant warping of the base or pole channel
- [ ] Thumbscrew threads cleanly with no binding or stringing
- [ ] Dry test: mount on pole without contents, apply firm downward pressure — box must not slide
- [ ] Box sits level on the pole without rocking or side-to-side movement

If any check fails, **do not use the part** — reprint with corrected settings.

!!! warning "Over-Tightening Risk"
    Once mounted, tighten the thumbscrew hand-tight plus one quarter-turn only.
    Over-tightening is the primary cause of box failure even in correctly
    printed parts. See the [Assembly Guide](assembly.md) for tightening instructions.

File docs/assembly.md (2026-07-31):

# v1 Accessory Box — Assembly

!!! warning "Before You Start"
    Verify your printed parts pass all checks in the [Print Guide](print-settings.md)
    before assembly. Do not use parts with visible layer delamination, cracking,
    or significant warping.

## What You Need

| Item | Source |
|---|---|
| Printed accessory box (`OpenPoleMount_IV-Pole_v1.stl`) | Print 1x |
| Printed thumbscrew (`thumbscrew_v14_flat_Thandle.stl`) | Print 1x |
| Standard home IV pole (~25mm / 1 inch diameter) | Your existing equipment |
| Small supplies to store (wipes, spare caps, tubing, etc.) | Your existing supplies |

No tools required — assembly is fully hand-tightened by design.

---

## Assembly Steps

### Step 1 — Thread the thumbscrew

Insert the thumbscrew into the threaded hole on the side of the box.
Turn **clockwise** by hand until it fully engages, then back off 2–3 turns
so the pole channel is open enough to slide onto the pole.

### Step 2 — Slide onto the pole

Position the box on the IV pole at the height where you want it —
typically below an equipment cradle, and clear of walkways where it
could be bumped. The pole slides into the vertical channel on the back
of the box.

### Step 3 — Tighten

Turn the thumbscrew **clockwise** by hand until it firmly contacts the pole.
Give it one additional firm quarter-turn. The box should not slide when
you push down on it with moderate force.

!!! danger "Do Not Over-Tighten"
    Over-tightening can crack the printed part. Hand-tight plus one quarter-turn
    is sufficient. If the box slips at this tension, inspect the print quality
    and reprint if needed — do not force beyond hand-tight.

### Step 4 — Load the box

Place your small supplies into the box. Keep contents within the recommended
working load of **up to ~1.4 kg (3 lb)** — do not overfill above the rim, and
keep loose small items bagged inside the box so they don't spill if the pole
is bumped.

### Step 5 — Verify stability

Before leaving the box in use:

- [ ] Box does not slide down the pole under firm downward pressure
- [ ] Contents are not overfilled and do not shift enough to unbalance the box
- [ ] Box does not interfere with any tubing or lines running along the pole
- [ ] IV pole base is fully spread and stable on the floor

---

## Adjusting Height

To reposition:

1. Remove the contents from the box
2. Loosen the thumbscrew 2–3 turns
3. Slide the box to the new height
4. Re-tighten the thumbscrew

Do not attempt to slide the box while it is loaded.

---

## Removal

1. Remove the contents from the box
2. Loosen the thumbscrew fully
3. Slide the box off the pole

---

## Troubleshooting

| Problem | Likely Cause | Solution |
|---|---|---|
| Box slides down the pole | Thumbscrew not tight enough or pole diameter too small | Tighten more; check pole diameter matches design spec |
| Box wobbles or contents shift | Overloaded or unevenly distributed contents | Redistribute contents; stay within the ~1.4 kg (3 lb) working load; verify pole diameter |
| Thumbscrew won't turn smoothly | Print stringing in threads or warped thread hole | Clean threads with brush; if damaged, reprint thumbscrew |
| Pole doesn't fit the channel | Pole diameter differs from design | [Open an issue](https://github.com/GoR-XarraY/openpolemount/issues) with your pole diameter |
| Part cracked during assembly | Over-tightening or under-printed | Reprint at ≥25% infill, ≥1 mm walls; hand-tighten only |

---

!!! info "Need Help?"
    If you're having trouble with assembly,
    [open an issue on GitHub](https://github.com/GoR-XarraY/openpolemount/issues).
    Include a photo if possible — we want to help.

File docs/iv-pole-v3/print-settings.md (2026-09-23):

# Print Guide — IV Pole Mount v3

!!! danger "Safety Note — Read First"
    This is a load-bearing mount, rated for equipment up to approximately
    **1.4 kg (3 lbs)**. Print quality directly affects safety.
    The settings below are **minimums** — you are responsible for verifying
    mechanical integrity before use. See [Safety & Disclaimer](../safety.md).

!!! success "STL Files Available Now"
    The finalized `OpenPoleMount_IV-Pole_v3.stl` is published and print-ready — download it
    [directly](https://github.com/GoR-XarraY/openpolemount/raw/main/stl/OpenPoleMount_IV-Pole_v3.stl)
    or from [GitHub Releases](https://github.com/GoR-XarraY/openpolemount/releases/latest).

    [**v2**](../iv-pole-v2/print-settings.md) also remains fully released and print-ready.

!!! info "V3 vs V2 — What's Different"
    IV Pole Mount v3 uses a **smaller, more form-fitting pocket** (~125 × 100 × 66 mm
    printed), redesigned from feedback on v2's more open pocket.
    The pole channel and thumbscrew interface are unchanged. **Print settings below
    carry over the same conservative minimums validated for v1/v2** — the v3 pocket
    itself has not yet been separately destruction-tested. Treat these as a starting
    point, not a substitute for your own inspection before use.

## Required Files

| File | Purpose | Quantity |
|---|---|---|
| [`OpenPoleMount_IV-Pole_v3.stl`](https://github.com/GoR-XarraY/openpolemount/raw/main/stl/OpenPoleMount_IV-Pole_v3.stl) | IV pole cradle (v3 shape) | 1 |
| [`OpenPoleMount_IV-Pole_v3_textured.stl`](https://github.com/GoR-XarraY/openpolemount/releases/download/v3.0.0/OpenPoleMount_IV-Pole_v3_textured.stl) | Optional variant — textured surface finish baked into the mesh (larger file, ~20 MB; same fit and print settings) | 1 (instead of the standard body) |
| [`thumbscrew_v14_flat_Thandle.stl`](https://github.com/GoR-XarraY/openpolemount/raw/main/stl/thumbscrew_v14_flat_Thandle.stl) | Thumbscrew for pole attachment (same part as v1/v2) | 1 |

!!! info "Testing Status — Pending"
    The [destruction testing](../testing.md) on file was performed on the v1/v2
    cradle body shape. **v3 has not yet been separately tested to failure.** The
    settings below are carried over from that testing as a conservative starting
    point because the pole channel, thumbscrew boss, and wall construction method
    are shared across all three versions — but this has not been independently
    confirmed for the v3 pocket geometry specifically. *(Pending George's
    confirmation/testing before this note can be upgraded to a tested claim.)*

## Material

**PLA** is the tested and validated material for this design family. Settings on
this page are based on PLA testing of v1/v2. Other materials (PETG, ASA, ABS) have
not yet been tested — if you print in another material, please share your results
by [opening an issue](https://github.com/GoR-XarraY/openpolemount/issues).

| Material | Status |
|---|---|
| **PLA** | ✅ Tested (v1/v2 geometry) — use the settings below |
| PETG / ASA / ABS | ⚠️ Not yet tested — proceed at your own risk |
| TPU / Flexible | ❌ Not suitable — cannot support structural load |

## Recommended Print Settings (PLA, carried over from v1/v2 testing)

| Setting | Cradle | Thumbscrew |
|---|---|---|
| Layer height | 0.2 mm | 0.2 mm |
| **Wall count** | **1 mm minimum (≈2–3 perimeters at 0.4 mm nozzle)** | **1 mm minimum** |
| **Top/bottom thickness** | **1 mm minimum** | **1 mm minimum** |
| **Infill** | **25% minimum — any non-concentric pattern (grid, gyroid, cubic, etc.)** | **25% minimum** |
| Infill pattern | Grid, gyroid, cubic, or similar — **not** concentric | same |
| Supports | None needed | Optional — single layer keeps part in place; brim works too |
| Print speed | 40–60 mm/s | 40–60 mm/s |

!!! danger "Wall and Infill Minimums Are Safety-Critical"
    Testing on the v1/v2 shape has shown that the mount **can crack if
    over-tightened** when walls or infill are below these minimums. The 1 mm wall +
    1 mm top/bottom + 25% non-concentric infill combination is the recommended
    minimum until v3-specific testing is complete.

    **Do not use concentric infill** — it does not provide
    the same resistance to the stress concentration from the thumbscrew.

## Part Orientation

**Cradle:** Print with the pole channel vertical (mounting hole facing up). This
orients layer lines perpendicular to the primary load direction, maximizing
pull-out and shear strength.

**Thumbscrew:** Print flat with the T-handle face down. No supports needed.

## Support Settings

Neither part requires supports. Supports are optional on both:

- **Cradle:** supports are not required. If you use them, place under the equipment cradle pocket. Tree or Normal both work; 45° threshold; 2–3 interface layers for clean removal.
- **Thumbscrew:** supports are not required. If enabled, the slicer typically places a single layer under the part — this helps hold it in place during printing. A brim works equally well for this purpose.

## Post-Processing

After printing:

1. Remove all supports carefully — use flush cutters, not a knife
2. Clean the thumbscrew threads with a brush if needed
3. Test-fit thumbscrew in the threaded hole — should turn smoothly by hand
4. Verify the pole channel diameter matches your IV pole
5. Check device fits snugly in the cradle pocket — should not rattle

## Verification Before Use

Run through this checklist before mounting any equipment:

- [ ] No visible layer delamination (check by pressing firmly — should not crack or flex excessively)
- [ ] No significant warping of the base or pole channel
- [ ] Thumbscrew threads cleanly with no binding or stringing
- [ ] Dry test: mount on pole without equipment, apply firm downward pressure — cradle must not slide
- [ ] Device seats fully without rocking or side-to-side movement — **pending George's own
      physical fit-test report on the finished v3 print; the photos on the
      [overview page](index.md) show a successful hand-fit but have not been logged
      as a formal verification pass**

If any check fails, **do not use the part** — reprint with corrected settings.

!!! warning "Over-Tightening Risk"
    Once mounted, tighten the thumbscrew hand-tight plus one quarter-turn only.
    Over-tightening is the primary cause of cradle failure even in correctly
    printed parts. See the [Assembly Guide](assembly.md) for tightening instructions.

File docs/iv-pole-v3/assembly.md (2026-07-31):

# Assembly Guide — IV Pole Mount v3

!!! warning "Before You Start"
    Verify your printed parts pass all checks in the [Print Guide](print-settings.md)
    before assembly. Do not use parts with visible layer delamination, cracking,
    or significant warping.

!!! info "V3 vs V1/V2 — What's Different"
    The assembly process for v3 is identical to v1 and v2. The v3 cradle has a
    smaller, more form-fitting pocket shaped around the equipment, but the
    same pole channel, thumbscrew interface, and OpenPoleMount block standard.
    These instructions apply to all three versions.

## What You Need

| Item | Source |
|---|---|
| Printed cradle ([`OpenPoleMount_IV-Pole_v3.stl`](https://github.com/GoR-XarraY/openpolemount/raw/main/stl/OpenPoleMount_IV-Pole_v3.stl) — see [Print Guide](print-settings.md)) | Print 1x |
| Printed thumbscrew (`thumbscrew_v14_flat_Thandle.stl`) | Print 1x |
| Standard home IV pole (~25mm / 1 inch diameter) | Your existing equipment |
| Your device (equipment to be mounted) | Your existing equipment |

No tools required — assembly is fully hand-tightened by design.

---

## Assembly Steps

### Step 1 — Thread the thumbscrew

Insert the thumbscrew into the threaded hole on the side of the cradle.
Turn **clockwise** by hand until it fully engages, then back off 2–3 turns
so the pole channel is open enough to slide onto the pole.

T-handle thumbscrew close-up on V3 mount
*T-handle thumbscrew threaded into the mount — hand-tight only*

### Step 2 — Slide onto the pole

Position the cradle on the IV pole at the height where you want the device.
The pole slides into the vertical channel on the back of the cradle.

### Step 3 — Tighten

Turn the thumbscrew **clockwise** by hand until it firmly contacts the pole.
Give it one additional firm quarter-turn. The cradle should not slide when
you push down on it with moderate force.

V3 mount rear view — pole clamp and thumbscrew
*Rear/underside view showing the thumbscrew boss engaged with the pole*

!!! danger "Do Not Over-Tighten"
    Over-tightening can crack the printed part. Hand-tight plus one quarter-turn
    is sufficient. If the cradle slips at this tension, inspect the print quality
    and reprint if needed — do not force beyond hand-tight.

### Step 4 — Install your device

Lower your device into the cradle from above. Because the v3 pocket is
form-fitted to the equipment body, it should seat snugly with very little side play.
Verify the device is fully seated and does not rock or tip.

Equipment cradle v3 — device seated
*The device seats in the pocket with the front face accessible, cabling free to exit*

### Step 5 — Verify stability

Before connecting any IV line:

- [ ] Cradle does not slide down the pole under firm downward pressure
- [ ] Device does not tip or rock in the cradle
- [ ] Cabling can exit the device without creating strain on the mount
- [ ] IV pole base is fully spread and stable on the floor

V3 mount — 3/4 angle view
*Completed installation — device in the form-fitting v3 cradle, mount secure on pole*

---

## Adjusting Height

To reposition:

1. Remove the device from the cradle
2. Loosen the thumbscrew 2–3 turns
3. Slide the cradle to the new height
4. Re-tighten the thumbscrew

Do not attempt to slide the cradle while the device is seated in it.

---

## Removal

1. Disconnect any lines or cabling from the device first (follow your care provider's instructions)
2. Lift the device straight up out of the cradle
3. Loosen the thumbscrew fully
4. Slide the cradle off the pole

---

## Troubleshooting

| Problem | Likely Cause | Solution |
|---|---|---|
| Cradle slides down the pole | Thumbscrew not tight enough or pole diameter too small | Tighten more; check pole diameter matches design spec |
| Device doesn't seat fully / feels tight | Print tolerance/shrinkage variance — v3's pocket is form-fitted with less clearance than v2 | [Open an issue](https://github.com/GoR-XarraY/openpolemount/issues) with your printer/material; v2's more open pocket is a fallback |
| Thumbscrew won't turn smoothly | Print stringing in threads or warped thread hole | Clean threads with brush; if damaged, reprint thumbscrew |
| Pole doesn't fit the channel | Pole diameter differs from design | [Open an issue](https://github.com/GoR-XarraY/openpolemount/issues) with your pole diameter |
| Part cracked during assembly | Over-tightening or under-printed | Reprint at ≥25% infill, ≥1 mm walls; hand-tighten only |

---

!!! info "Need Help?"
    If your device doesn't fit or you're having trouble with assembly,
    [open an issue on GitHub](https://github.com/GoR-XarraY/openpolemount/issues).
    Include a photo if possible — we want to help.

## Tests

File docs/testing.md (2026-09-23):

# Strength Testing

!!! info "Scope of this testing"
    This destruction testing was performed on the v1/v2 cradle body shape. The
    v3 pocket (smaller, more form-fitted) shares the same
    pole channel, thumbscrew boss, and wall construction method, but **has not yet
    been separately tested to failure**. See the
    [v3 Print Guide](iv-pole-v3/print-settings.md) for current status.

## Summary

OpenPoleMount v1 was tested to destruction on 2026-06-09 using a deliberately under-spec print.
**The mount never failed under load.** When pushed far beyond any realistic use to find the
failure point, the failure mode was safe and predictable — and crucially, **the broken mount
continued to hold on the pole after failure.**

---

## Test Print Settings

These settings are **intentionally at or below the recommended minimums** — the goal was
to find the failure point of a worst-case print.

| Parameter | Test value | Recommended minimum |
|---|---|---|
| Material | Standard PLA | PLA |
| Wall count | 4 walls | ≥1 mm |
| Top/bottom | 1 mm | ≥1 mm |
| Infill | 15%, non-structural pattern | ≥25%, non-concentric (grid OK) |

---

## Test 1 — Thumbscrew Over-Tightening to Failure

**Video:** `PXL_20260609_072444167.mp4`

The mount is clamped to a test rig with a chrome rod through the pole channel.
The thumbscrew is progressively tightened far beyond the hand-tight + quarter-turn
instruction — sustaining deliberate force well past any normal use.

The video shows the failure sequence in real time:

1. The mount holds firmly through all normal tightening levels
2. Continued extreme force initiates a crack at the thumbscrew hole in the side wall
3. The crack propagates through the wall as over-tightening continues
4. The thumbscrew punches through the side wall at the point of failure

The **pole channel and cradle body remain completely intact throughout.** Only the
side wall at the thumbscrew hole fails, and only under sustained force that no
user would apply in normal operation.

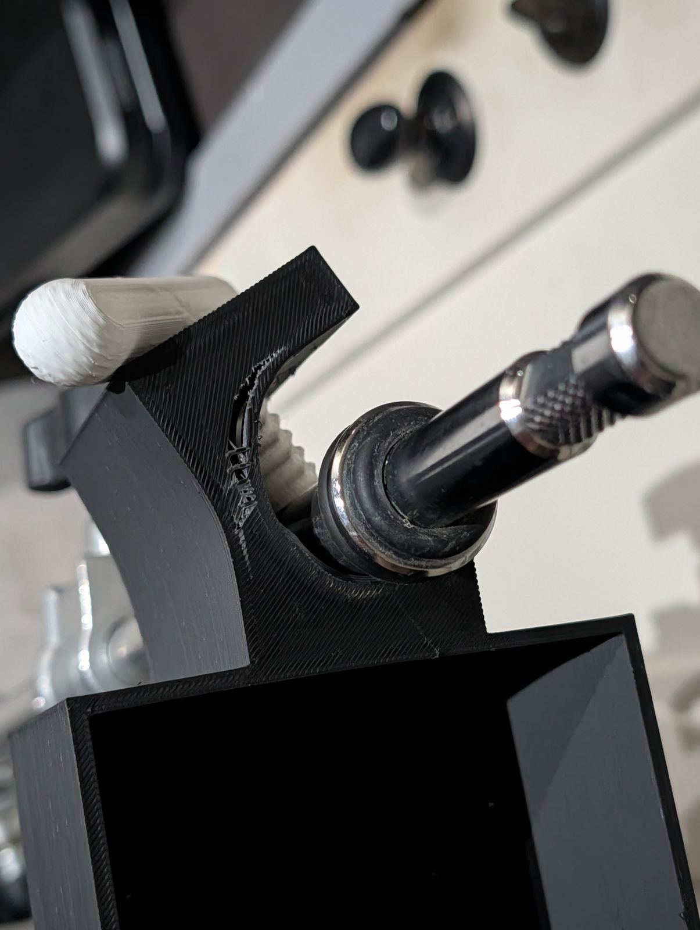
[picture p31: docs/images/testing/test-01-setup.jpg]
Test setup — mount on rig before failure

*Mount on test rig before failure — chrome rod through pole channel, thumbscrew being tightened*

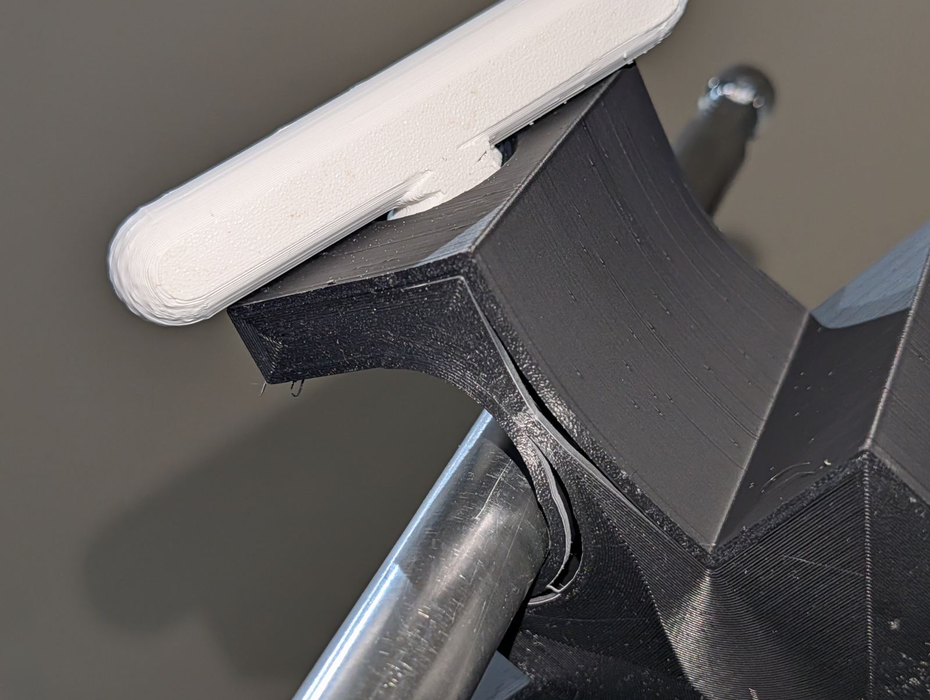
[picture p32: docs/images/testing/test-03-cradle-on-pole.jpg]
Crack propagating during failure

*Crack initiating and propagating at the thumbscrew hole during extreme over-tightening*

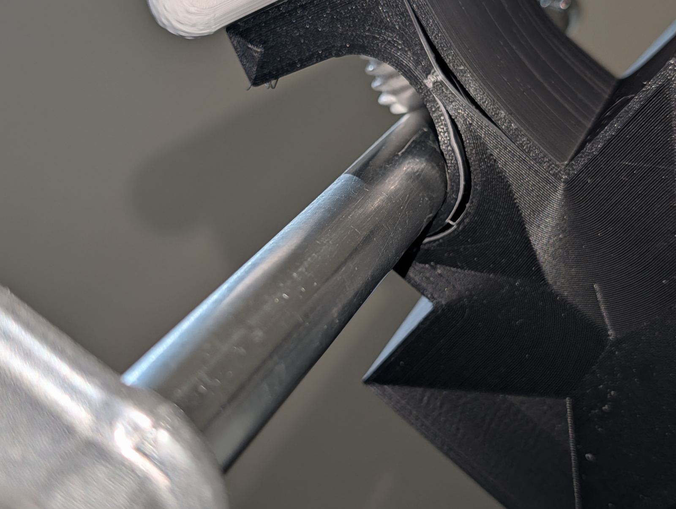
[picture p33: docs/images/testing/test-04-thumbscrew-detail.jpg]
Close-up of failure point

*Thumbscrew engagement zone — close-up showing wall stress during tightening*

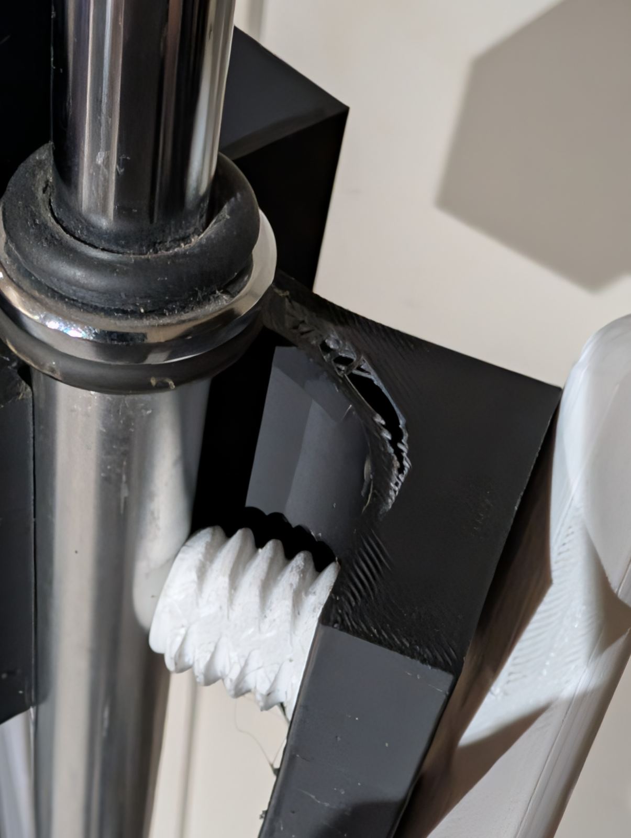
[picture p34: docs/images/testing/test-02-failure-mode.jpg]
Final failure state

*End state: thumbscrew has punched through the side wall. Pole channel intact.*

---

## Test 2 — Broken Mount Still Holds

**Video:** `PXL_20260609_072737644.mp4`

After the side wall failure in Test 1, the broken mount was left on the pole and tested
for continued grip. This is the most important finding of the test session.

**With the thumbscrew hole completely torn open, the mount continued to hold on the pole.**

The video shows the broken cradle being pushed, pulled, and loaded on the pole. Despite
the visible damage to the side wall, the pole channel geometry maintains grip. The mount
does not slide or release. A load can still be hung from it.

This demonstrates two critical properties of the design:

1. **Failure is visible and obvious** — a broken mount looks broken. There is no hidden
   or gradual weakening that could go undetected.
2. **Failure is not catastrophic** — the broken mount retains residual grip. Equipment
   hanging from a failed mount would not suddenly drop; there would be time to
   notice and address the problem.

---

## Key Findings

### The design has a generous safety margin
A deliberately under-spec print — well below recommended minimums — survived all normal
use conditions without any failure. The recommended settings provide meaningful additional
margin above even this worst-case baseline.

### The failure mode is safe
When the mount does fail (under extreme, sustained over-tightening):
- Failure is localised to the thumbscrew side wall only
- The pole channel remains intact
- The failure is immediately visible
- The mount retains residual grip after failure

### Over-tightening is the only realistic failure path
Normal hand-tightening cannot reach the force levels required to cause failure.
The failure in testing required sustained deliberate force far beyond what is needed
to securely mount the cradle. **Do not over-tighten.** See [Assembly Guide](iv-pole-v3/assembly.md).

---

## What This Means for the Recommended Settings

Our [recommended settings](iv-pole-v3/print-settings.md) (≥1 mm walls, ≥1 mm top/bottom, ≥25% non-concentric infill)
are conservative relative to these tested limits. The conservatism is intentional:

- Print quality varies between printers and operators
- PLA quality varies between brands and batches
- 25% infill (vs. 15% in the test) adds margin over the tested worst case; top/bottom thickness matches the tested print

Printing at or above the recommended settings gives significant margin beyond what was
already demonstrated to survive in this test.

---

## Videos

### Test 1 — Thumbscrew Breaking the Mount

Shows the mount being tightened to destruction in real time — crack initiation at the thumbscrew
hole, propagation through the side wall, and the final punch-through. The pole channel and cradle
body remain intact throughout.

<div style="display:flex;justify-content:center;margin:1.5rem 0;">
  <iframe width="315" height="560"
    src="https://www.youtube.com/embed/OXBP-LRRCT0"
    title="OpenPoleMount — Test 1: Thumbscrew Breaking the Mount"
    frameborder="0"
    allow="accelerometer; autoplay; clipboard-write; encrypted-media; gyroscope; picture-in-picture"
    allowfullscreen>
  </iframe>
</div>

### Test 2 — Broken Mount Still Holds

After the side wall failure in Test 1, the broken mount is left on the pole and loaded.
Despite the thumbscrew hole being completely torn open, the pole channel geometry maintains grip —
the mount does not slide or release. Confirms the design's safe, residual-hold failure mode.

<div style="display:flex;justify-content:center;margin:1.5rem 0;">
  <iframe width="315" height="560"
    src="https://www.youtube.com/embed/5i2bdpntpkQ"
    title="OpenPoleMount — Test 2: Broken Mount Still Holds"
    frameborder="0"
    allow="accelerometer; autoplay; clipboard-write; encrypted-media; gyroscope; picture-in-picture"
    allowfullscreen>
  </iframe>
</div>

---

*Testing conducted by the OpenPoleMount project creator, 2026-06-09.*  
*This testing is provided for informational purposes only and does not constitute*
*engineering certification or safety approval. See [Safety & Disclaimer](safety.md).*

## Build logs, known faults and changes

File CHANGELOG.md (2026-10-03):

# Changelog

All notable changes to this project will be documented in this file.

The format is based on [Keep a Changelog](https://keepachangelog.com/en/1.0.0/),
and this project uses semantic versioning.

## 2026-10-03 — OSHWA certified open source hardware
- OSHWA certified the v1 accessory box (US002862), the v2 universal holder (US002863) and the v3 cradle (US002864); the first listing, US002834, dates from 2026-07-10.
- New Certification page, homepage banner, certification marks on the v1/v2/v3 pages, README table. Official mark files (unaltered, downloaded from each certificate page) in docs/images/oshwa/ (SVG) and press/oshwa/ (PNG).

## [Unreleased]

### 2026-09-28
- **Order page: v3 PETG Black listing replaced** (Teleport item 8264 → 8299). The old
  item's card under "Other options" showed the thumbscrew instead of the cradle, and
  Teleport's default-image setting would not save; the new item lists the cradle first.
  Same title, description, files, filament and $30 price. Item 8264 is disabled, not deleted.

### 2026-09-22
- **Print minimums now match Slant 3D's actual Teleport profile** (0.2 mm layers,
  1 mm walls on every face, 25% grid infill): the 3D-honeycomb preference and the
  "no grid" rule were dropped, and the top/bottom minimum is now 1 mm. The order page's
  old "6 walls / 35% honeycomb" production spec was wrong and has been corrected.
- **v3 is now orderable** in PETG (Black, White, Carbon Fiber) via Slant 3D / Teleport,
  $30 + shipping; v2 stays available in PLA ($25 + shipping).
- Removed "at cost / no profit" wording from the homepage, README and v2 page.
- Order page now notes that PETG has not yet been strength-tested by the project.

### Added
- IV Pole Mount v3 documentation (`docs/iv-pole-v3/`) — overview/photos, print guide,
  assembly guide — a smaller, more form-fitting cradle pocket, built from user
  feedback on v2
- 9 new v3 product photos, processed and published under `docs/images/iv-pole-v3/`
- v3 promoted to the primary/lead design on the homepage, README, and nav

### Changed
- v2 repositioned as a **universal device holder**: the CMS6000-specific
  recommendation was removed; v2 now documents that its more open pocket may fit
  several infusion pumps or other devices, with no confirmed compatibility list yet,
  and invites community fit reports
- Homepage, README, nav, and social share image (OG/Twitter) updated to lead with v3
- `docs/testing.md` — added a scope note clarifying the destruction testing applies to
  the v1/v2 shape; v3 has not yet been separately tested
- **Non-device framing pass** — README, website docs, and social/SEO metadata reworded
  to describe OpenPoleMount as general-purpose mounting hardware (universal equipment
  cradle) rather than a pump-specific accessory. Specific-pump fitment is now presented
  only as user-reported example/community fit notes, not as manufacturer claims. Keeps
  the project a non-medical-device under FDA's intended-use framework. See
  `REGULATORY-CLASSIFICATION.md` (repo root — intentionally outside the docs site)

### Known Issues / Pending
- ~~v3 STL release files are not yet published~~ — resolved 2026-07-28: `stl/OpenPoleMount_IV-Pole_v3.stl`
  is published and linked from the site. Print-on-demand ordering for v3 is still pending (v2 remains
  the orderable version).

## [1.1.0] - 2026-06-17

### Added
- IV Pole Mount v2 (`OpenPoleMount_IV-Pole_v2.stl`) — revised exterior shape, functionally identical to v1
- Documentation for IV Pole Mount v2 (same specs, print settings, and assembly as v1)
- Variant comparison table on the home page

## [1.0.0] - 2026-06-08

### Added
- Initial release: IV pole cradle for Curlin CMS6000 infusion pump (`OpenPoleMount_IV-Pole_v1.stl`)
- Thumbscrew for pole attachment (`thumbscrew_v14_flat_Thandle.stl`)
- CERN-OHL-W-2.0 hardware license
- CC-BY-SA-4.0 documentation license
- Medical liability disclaimer (DISCLAIMER.md)
- Documentation website at openpolemount.com
- Print guide with material and infill requirements
- Assembly instructions
- Contributing guide and Code of Conduct

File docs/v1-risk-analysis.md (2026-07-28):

---
title: v1 Accessory Box — Risk Analysis
description: Risk analysis for the OpenPoleMount v1 accessory box — hazards, failure modes, and mitigations for a pole-mounted 3D-printed storage box.
---

# v1 Accessory Box — Risk Analysis

This page assesses the risks specific to the **v1 accessory box**. It is a passive,
non-powered, 3D-printed storage box built on the OpenPoleMount mounting block.

!!! info "General-purpose hardware — no medical function"
    The v1 accessory box is general-purpose mounting hardware with **no medical
    function** — it holds small personal items and supplies. It is **not a medical
    device.** The only hazard category is **mechanical**. See the
    [Safety & Disclaimer](safety.md).

## Shared clamp risks

The v1 box attaches with the same block-and-thumbscrew clamp as every OpenPoleMount
design. Those load-bearing hazards (slip, overload, thumbscrew over-tightening,
weak/mis-oriented print, material creep) and their mitigations are covered once in
the **[Mounting Block Risk Analysis](mounting-block/risk-analysis.md)** — read it
alongside this page.

## Load rating

Recommended working load: **up to ~1.4 kg (3 lb)** of contents, as a conservative
starting point at the recommended print settings. Do not overfill.

## v1-specific hazards

| # | Hazard | Cause | Effect | Mitigation |
|---|---|---|---|---|
| 1 | Contents fall out | Box overfilled or tilted; loose small items | Items drop to the floor | Keep contents within the box; don't overfill above the rim; store small loose items in a bag inside the box. |
| 2 | Overloaded box | Contents heavier than the load rating | Box or clamp strain over time | Stay within ~1.4 kg of contents; use PETG for heavier or sustained loads. |
| 3 | Used as a device cradle | Mistaking the box for an equipment cradle | A seated device's front face is not accessible in the v1 pocket | Use v1 **only as a storage box**; for holding a device with its controls accessible, use [v3](iv-pole-v3/index.md) or [v2](iv-pole-v2/index.md). |
| 4 | Snag/knock | Box protrudes from the pole | Bumped in a walkway | Mount below the cradle and clear of walkways; keep the pole base stable. |

## Evidence

The load-bearing clamp was validated in [destruction testing](testing.md), which
was performed on the **v1/v2 body shape**: a deliberately under-spec print never
failed under normal load, the failure mode was safe and visible, and the broken
mount retained residual grip.

## Points of failure

| Point | Consequence | Detectability | Net risk |
|---|---|---|---|
| Block/thumbscrew clamp | See block analysis | Visible; residual grip | Low with correct install |
| Box contents | Items fall if overfilled/tilted | Visible | Low with sensible loading |
| Print integrity | Weak part if settings/orientation wrong | Inspection + hand flex-test | Low with adherence to print guide |

---

*Informational only; not engineering certification or regulatory approval. See the
[Safety & Disclaimer](safety.md).*

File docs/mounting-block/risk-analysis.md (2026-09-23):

---
title: Mounting Block — Risk Analysis
description: Risk analysis for the OpenPoleMount mounting block — hazards, failure modes, and mitigations for a 3D-printed pole clamp.
---

# Mounting Block — Risk Analysis

This page estimates and assesses the risks of the OpenPoleMount mounting block, its
failure modes, and how they are mitigated. It follows the spirit of a lightweight
ISO 14971-style analysis, scaled to what the part actually is: a **passive,
non-powered, 3D-printed pole clamp**.

!!! info "Scope & nature of the part"
    OpenPoleMount is **general-purpose mounting hardware — not a medical device.**
    It has no electrical, chemical, or software function, no patient contact, and
    no role in delivering, controlling, or supporting medication or therapy. The
    single hazard category is **mechanical**: the secure retention of whatever is
    mounted on a pole. See the [Safety & Disclaimer](../safety.md).

## Summary of residual risk

The dominant risk is a mounted object shifting or falling if the mount is
mis-printed, overloaded, or mis-installed. This is mitigated by conservative,
documented print settings; a stated load rating; a simple installation procedure;
and — demonstrated by [destruction testing](../testing.md) — a **safe, visible,
non-catastrophic failure mode that retains residual grip** rather than releasing
suddenly. With the recommended settings and correct installation, residual risk is
low for the intended general pole-mounting use.

## Load rating

Recommended working load: **up to ~1.4 kg (3 lb)** per mount, as a conservative
starting point at the recommended print settings. Actual capacity depends on
material, print quality, and pole fit — verify safe support of your own load before
relying on it.

## Hazard / risk table

| # | Hazard | Cause | Potential effect | Mitigation |
|---|---|---|---|---|
| 1 | Mount slips or rotates on the pole | Thumbscrew under-tightened; pole diameter outside the channel's range; dusty/greasy pole | Mounted object shifts or drops | Hand-tighten + ¼ turn; match the pole diameter (resize the model if needed); clean the pole. Grip is by printed channel geometry, not just friction. |
| 2 | Overload | Object heavier than the ~1.4 kg rating; shock/jerk loads | Part deformation or failure | Respect the stated load rating; avoid impact loads; use PETG and/or higher infill for heavier objects. |
| 3 | Thumbscrew over-tightened to failure | Sustained force far beyond hand-tight | Crack propagates and the thumbscrew punches through the side wall | **Do not over-tighten** (documented in the [Assembly Guide](../iv-pole-v3/assembly.md)). Testing shows this requires force no normal user applies, the pole channel stays intact, failure is **immediately visible**, and the broken mount **retains residual grip**. |
| 4 | Weak print | Concentric infill pattern or infill below 25%, too few walls, under-extrusion, layer delamination | Reduced strength; premature failure under load | Follow the [Print Guide](../iv-pole-v3/print-settings.md) minimums (≥1 mm walls, 2 mm top/bottom, ≥25 % 3D honeycomb); inspect each print; flex-test by hand before use. |
| 5 | Wrong print orientation | Block printed with layers parallel to the clamp load | Layer-line splitting under clamping force | Print the block with the pole channel **vertical** (layers perpendicular to load), thumbscrew flat — per the print guide. |
| 6 | Material creep / heat softening | PLA under sustained load, or in a warm environment (PLA softens ~60 °C) | Slow deformation / loss of grip over time | Use **PETG** for sustained-load or warm conditions; inspect periodically; do not place near heat sources; re-check tightness. |
| 7 | Pole damage | Excessive clamping torque | Marring of the pole | The printed clamp face is far gentler than metal hardware by design; use only the specified torque. This is a **reduced** risk versus metal clamps. |
| 8 | Undetected degradation | UV exposure, repeated stress cycles, ageing filament | Gradual weakening | Failure mode is visible, not hidden (see testing); inspect before each use; reprint if cracked, warped, or flexing. |

## Evidence: destruction testing

A deliberately **under-spec** print (below recommended minimums) was tested to
destruction on 2026-06-09. Key results:

- It **never failed under normal load** — the failure point was only reached under
  extreme, sustained thumbscrew over-tightening far beyond any real use.
- Failure was **localised** to the thumbscrew side wall; the pole channel and body
  stayed intact.
- The failure was **immediately visible** — no hidden or gradual weakening.
- The broken mount **still held on the pole** (residual grip) — a mounted object
  would not suddenly drop; there is time to notice and act.

The recommended settings are ~2× the wall thickness of that worst-case test print,
giving a generous margin. Full write-up and video: **[Strength Testing](../testing.md)**.

## Mitigation & maintenance summary

- Print at or above the recommended minimums, in the correct orientation.
- Inspect each printed part; reject any with cracks, warping, delamination, or flex.
- Match (or resize to) your pole diameter.
- Hand-tighten plus a quarter turn — **do not over-tighten**.
- Stay within the ~1.4 kg load rating; use PETG for heavier or warmer use.
- Re-inspect and re-check tightness periodically; reprint if any damage appears.

## Points of failure (single-point summary)

| Point of failure | Consequence | Detectability | Net risk |
|---|---|---|---|
| Thumbscrew side wall | Localised crack under gross over-tightening | Immediately visible; residual grip retained | Low |
| Pole channel grip | Slip if under-tightened or wrong pole size | Visible/felt on install and load test | Low with correct install |
| Print integrity | Weak part if settings/orientation wrong | Detectable by inspection and hand flex-test | Low with adherence to guide |

---

*This analysis is provided for informational purposes only and does not constitute
engineering certification or regulatory approval. See the
[Safety & Disclaimer](../safety.md).*

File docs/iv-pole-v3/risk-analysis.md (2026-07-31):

---
title: Cradle v3 — Risk Analysis
description: Risk analysis for the OpenPoleMount v3 cradle — hazards, failure modes, and mitigations for a form-fitting 3D-printed IV-pole cradle.
---

# Cradle v3 — Risk Analysis

This page assesses the risks specific to the **v3 cradle**. It is a passive,
non-powered, 3D-printed part built on the OpenPoleMount mounting block.

!!! info "General-purpose hardware"
    The v3 cradle is general-purpose mounting hardware — **not a medical device.**
    No electrical, chemical, or software function; no patient contact; no role in
    delivering or controlling therapy. The only hazard category is **mechanical**.
    See the [Safety & Disclaimer](../safety.md).

## Shared clamp risks

The v3 cradle attaches with the same block-and-thumbscrew clamp as every
OpenPoleMount design. Those load-bearing hazards (slip, overload, thumbscrew
over-tightening, weak/mis-oriented print, material creep) and their mitigations are
covered once in the **[Mounting Block Risk Analysis](../mounting-block/risk-analysis.md)**
— read it alongside this page.

## Load rating

Recommended working load: **up to ~1.4 kg (3 lb)**, as a conservative starting
point at the recommended print settings. Verify safe support of your own load first.

## v3-specific hazards

| # | Hazard | Cause | Effect | Mitigation |
|---|---|---|---|---|
| 1 | Object does not seat fully | Object larger than the form-fitting pocket | Poor seating; object sits high or proud | v3's pocket is sized to hold a compact device (body prints at about 125 × 100 × 66 mm — see the [BOM](../cradle-bom.md)). Check your object fits before relying on it; use [v2](../iv-pole-v2/index.md) for a more open pocket, or resize the model. |
| 2 | Object rocks in the pocket | Object smaller than the pocket | Movement under load | The form-fitting v3 pocket minimises this vs. an open holder, but confirm a snug fit; add a shim or reprint scaled if loose. |
| 3 | Front face obstructed | Object oriented wrong way in the pocket | Controls/screen not reachable | Seat the object with its front face outward — the v3 pocket is shaped to keep the front accessible. |
| 4 | Cabling strain | Cable/tubing routed under tension | Pull on the mount or the object | Route cabling with slack so it exits without tension (see [Assembly](assembly.md)). |

## Evidence

The load-bearing clamp shared by v3 was validated in
[destruction testing](../testing.md): a deliberately under-spec print never failed
under normal load, the failure mode was safe and visible, and the broken mount
retained residual grip. The v3 body reuses that same clamp geometry; its
form-fitting pocket has not been separately tested to failure.

## Points of failure

| Point | Consequence | Detectability | Net risk |
|---|---|---|---|
| Block/thumbscrew clamp | See block analysis | Visible; residual grip | Low with correct install |
| Pocket fit | Object rocks or sits proud if mismatched | Felt on test-fit and load test | Low with correct-size object |
| Print integrity | Weak part if settings/orientation wrong | Inspection + hand flex-test | Low with adherence to print guide |

---

*Informational only; not engineering certification or regulatory approval. See the
[Safety & Disclaimer](../safety.md).*

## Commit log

2026-06-09 feat: initial release of OpenPoleMount v1.0.0
    - IV pole cradle for Curlin CMS6000 (STL + source placeholder)
    - Thumbscrew attachment (STL)
    - CERN-OHL-W-2.0 hardware license + CC-BY-SA-4.0 docs license
    - Full medical disclaimer and safety documentation
    - MkDocs Material documentation site (deploys to openpolemount.com)
    - GitHub Actions auto-deploy to GitHub Pages
    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
    [OpenPoleMount_IV-Pole_v1.stl, thumbscrew_v14_flat_Thandle.stl]
2026-06-09 docs: update print settings with tested PLA values (2mm walls, 2mm top/bottom, 15% non-concentric infill, 3D honeycomb preferred; mount can crack if over-tightened below minimums)
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2026-06-09 docs: add destruction testing results (mount survived; only failed at extreme over-tightening)
2026-06-09 test: add destruction test photo - failure mode (thumbscrew punch-through at extreme over-tightening)
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2026-06-09 docs: update testing page with accurate video descriptions from ffmpeg frame analysis
2026-06-10 Update recommended print settings: 6 walls, 35% infill, 2mm top/bottom
    Walls raised from 2mm to 6 walls (~2.4mm at 0.4mm nozzle).
    Infill raised from 15% to 35% minimum.
    Top/bottom unchanged at 2mm.
    Updated print-settings, testing, safety, and assembly docs consistently.
2026-06-12 fix: supports are optional on both parts, not required
    - Cradle: no supports needed (optional)
    - Thumbscrew: no supports needed (optional — can improve thread definition)
    - Update Support Settings section body to match
2026-06-12 fix: thumbscrew supports — single layer helps hold part in place, brim also works
2026-06-17 Add IV Pole Mount v2 — STL, 3D render, product photos, full docs
    Files added:
    - stl/OpenPoleMount_IV-Pole_v2.stl (v2 body, different shape, same specs)
    - docs/iv-pole-v2/index.md (overview with STL render + 4-photo gallery; og:image set)
    - docs/iv-pole-v2/print-settings.md (full print guide)
    - docs/iv-pole-v2/assembly.md (step-by-step with inline photos)
    - docs/images/iv-pole-v2/v2-stl-render.jpg (Blender render, chrome-cropped)
    - docs/images/iv-pole-v2/v2-og-image.jpg (1200x630 OG/social preview image)
    - docs/images/iv-pole-v2/v2-mounted-*.jpg (5 product photos, EXIF-corrected)
    Updated:
    - mkdocs.yml — V2 nav section (Overview & Photos, Print Guide, Assembly)
    - docs/index.md — variant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
    [OpenPoleMount_IV-Pole_v2.stl]
2026-06-17 Add V2 printing footage embed (teleportpod)
    - Overview page: printing footage iframe above photo gallery
    - Print guide: printing footage section after settings table
2026-06-17 Add 'Order a Print' page — $25 + shipping via teleportpod
    - docs/order.md: dedicated ordering page with teleportpod embed, specs table,
    3-stat header (price / parts / tools), safety disclaimer
    - docs/index.md: prominent 2-column CTA card (Print Free vs Order $25)
    - docs/iv-pole-v2/index.md: matching 2-column CTA card below photo gallery
    - mkdocs.yml: 'Order a Print ($25)' added to nav as second item
2026-06-17 Expand teleportpod iframes to full height — no internal scroll
    - order.md: height 800→1500px
    - iv-pole-v2/index.md: 315x560 → 500x1500
    - iv-pole-v2/print-settings.md: 315x560 → 500x1500
    At 500px iframe width the portal content stacks vertically to ~1400px;
    800px caused a scrollbar inside the frame.
2026-06-17 Link YouTube Shorts to site — printing footage and strength tests
    - testing.md: replace placeholder video IDs with actual Shorts
    - Test 1 (torture test): OXBP-LRRCT0
    - Test 2 (broken mount still holds): 5i2bdpntpkQ
    - iv-pole-v2/index.md: replace teleportpod iframe with printing Short z05xgJhH_BQ
    - iv-pole-v2/print-settings.md: same printing Short z05xgJhH_BQ
2026-06-21 feat: update social share OG image from V1 to V2 design
    Replace the V1 Blender screenshot hero.png with the V2-specific OG image
    (v2-og-image.jpg, 1200x630) so Facebook/Instagram/Twitter link previews
    show the current design.
2026-06-21 feat: add 12 new installed photos to V2 gallery
    - Curlin CMS6000: front, side, straight-on, overhead angle
    - MOOG pump: front-left, front-right, top-down
    - Empty cradle: front, side, top, rear, channel detail
    All photos EXIF-transposed and resized to 1200px max.
    Photos organized into three subsections on the V2 overview page.
2026-06-21 fix: correct pump identification — all photos are Curlin CMS6000, not MOOG
    Rename v2-moog-*.jpg files to v2-curlin-back-*.jpg / v2-curlin-top2.jpg.
    Remove 'MOOG Pump Compatibility' section; merge all 7 Curlin views into
    one 'Curlin CMS6000 — More Views' grid. Fix all alt text and captions.
2026-06-27 feat: make IV Pole Cradle v2 the primary design; reframe printing as open-source-first
    Restructure the site so v2 — the current, functional pump cradle — is the hero
    across the homepage, nav, and README, and demote v1 to its honest role as a
    pole-mounted accessory box (not very functional as a pump cradle).
    Why: v2 is the design people should actually print for the Curlin CMS6000. The
    old site billed v1/v2 as equal "variants" and headlined a $25 pre-printed order,
    which read like a product. This project is open-source medical hardware, not a
    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
2026-06-27 fix: update safety checklist to match relaxed print spec (1mm walls, 25% infill)
2026-06-27 fix: repair .md href 404s in HTML blocks; give order card more presence
    MkDocs doesn't rewrite .md hrefs inside raw HTML — changed to /path/ slugs.
    Also bumped the 'No printer? Order a print' section from a tiny dim footnote
    to a small card with a button, so it's readable without competing with the DIY card.
2026-06-27 fix: correct v1 description — buttons not accessible, not just 'less secure'
    The real problem with v1 as a pump cradle is that the pump buttons and screen
    are not accessible when the pump is seated in it, making it non-functional.
    Previous wording ('doesn't seat as securely') was vague and inaccurate.
2026-07-15 feat: promote IV Pole Cradle v3 to lead design; reposition v2 as universal holder
    V3 is a smaller, more form-fitting cradle for the Curlin CMS6000, built from
    user feedback on v2's more open pocket. Adds full v3 documentation (overview
    w/ 9 new photos, print guide, assembly guide) mirroring v2's page structure,
    promotes v3 across the homepage/README/nav/social-share image, and reframes
    v2 as a universal device holder (no confirmed pump compatibility list yet,
    invites community fit reports) now that it's no longer the CMS6000-specific
    recommendation.
    V3 STL release files are not yet finalized (working files in stl/ don't match
    the release-ready v1/v2 naming/format), so print-on-demand orderi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
2026-07-15 feat: add Mounting Block v1 foundation page + STLs
    The Pole Mounting Block v1 is the base component every OpenPoleMount cradle and
    accessory is built on. New foundation page with the block + T-handle thumbscrew
    STLs, measured dimensions, shared print settings, and honest pending-spec/testing
    notes. Nav entry added (not the homepage lead — v3 stays the hero). Accessories
    page updated: standalone block now Published, links to the new page.
    [OpenPoleMount_Pole_Mounting_Block_ThandleThumbscrew-V1.stl, OpenPoleMount_Pole_Mounting_Block_V1.stl]
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2026-07-28 docs: add mounting-block BOM and risk analysis pages
    Add two documentation pages for the mounting block (the OSHWA-certified base
    component), plus nav entries:
    - BOM: fully 3D-printed, no proprietary parts; measured single-unit filament
    (thumbscrew ~14 g; full v3 cradle ~109 g PLA as reference); safety-critical
    print spec and measured dimensions.
    - Risk Analysis: ISO 14971-style hazard/mitigation table for a passive pole
    clamp, load rating, and the destruction-testing evidence (safe visible
    failure mode with residual grip).
    Both written as general-purpose mounting hardware (non-device), consistent with
    the rest of the docs. Provides real URLs for the OSHWA certification form.
    Co-A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
2026-07-28 feat: publish v3 STL; add per-cradle risk analysis pages
    - Publish the release-ready v3 cradle STL (stl/OpenPoleMount_IV-Pole_v3.stl,
    clean 632 KB mesh) and update all docs/README that said the v3 files were
    pending — v3 is now downloadable.
    - Split risk analysis into per-cradle pages (v3, v2, v1 accessory box), each
    covering version-specific hazards and referencing the shared mounting-block
    risk analysis for the load-bearing clamp. Gives each OSHWA cradle application
    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
    [OpenPoleMount_IV-Pole_v3.stl]
2026-07-31 fix: remove stale v3-unpublished banners; optimize testing images; harden gitignore
    The 2026-07-28 v3 STL publication sweep missed two pages that still said
    v3 print files "aren't published/finalized yet" (homepage banner, order
    page) — contradicting the working v3 download links on the same pages.
    Order page also called this a "medical hardware project"; aligned to the
    generic-hardware voice used everywhere else. Added direct links for the
    v2 + thumbscrew STLs in the homepage download table.
    Testing-page photos were 1.2-1.9 MB each (6.4 MB of a 9.1 MB site) —
    recompressed to <200 KB, visually unchanged, for phone users.
    Gitignore now covers internal task/audit/plan notes, photo stagin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
2026-07-31 fix: correct safety-critical print specs; remove false source-CAD and cert claims
    Content audit found the Safety page, v1 print guide, and testing page
    still publishing the old 1 mm wall / 25% infill minimums — roughly a
    third of the 6-wall / 2 mm / 35% spec every current print guide
    requires for the load-bearing clamp. All three now state the real
    minimums, and the testing page's "recommended" column no longer repeats
    its own worst-case test values.
    Four pages claimed editable Blender source lives under stl/ — no such
    files exist in the repo. Reworded to the truth: STLs are the published
    geometry, STEP exports are in preparation under source/. Also dropped
    an incorrect "certified" desc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
2026-07-31 feat: PETG photo gallery, v1 accessory-box rewrite, per-page OG images
    Three changes from tonight's build plan:
    - v3 page gains a "PETG print — textured finish" gallery: seven new
    photos (EXIF-stripped, ≤240 KB each) in the same community example-fit
    voice and layout as the existing galleries.
    - The v1 pages now consistently document the accessory box: assembly.md
    is a box assembly manual (pole clamp steps unchanged, device-seating
    and IV-line steps replaced with box loading/stability checks), and
    both v1 pages carry unambiguous titles. URLs unchanged.
    - Social share images are now per-section: v2 pages share the v2 photo,
    v1 pages the mounting-block render, everything else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
2026-07-31 feat: publish native Blender source files for all designs
    The editable-source gap is closed: the original .blend files for the
    v1/v2/v3 cradles and the mounting block are now in source/, satisfying
    OSHWA's editable-source requirement with a fully open-source toolchain.
    The four pages that described source as "in preparation" now point at
    the published files, and the contributing docs accept .blend as the
    project's native source format instead of demanding STEP — a format
    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
    [OpenPoleMount_IV-Pole_v1.blend, OpenPoleMount_IV-Pole_v2.blend, OpenPoleMount_IV-Pole_v3.blend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]
2026-07-31 feat: add thumbscrew source file; update mounting-block source
    George re-exported the mounting-block .blend and provided the T-handle
    thumbscrew as its own source file, completing the editable-source set —
    every published STL now has its native Blender source in source/.
    [OpenPoleMount_Pole_Mounting_Block_V1.blend, OpenPoleMount_Pole_THandle_Thumbscrew.blend]
2026-07-31 ci: pin mkdocs-material to 9.x in deploy workflow
    Completes the toolchain pin started in requirements.txt: the deploy
    workflow no longer installs whatever version is newest, so the
    announced MkDocs 2.0 breaking release cannot silently take down the
    site. Also adds a SECRETS.md.example template and gitignores the real
    SECRETS.md per project convention.
2026-07-31 docs: clarify PLA-vs-PETG filament figures came from different slicer profiles
    The v3 BOM row showed PETG using less filament than PLA for the same
    STL, which reads as physically impossible; George confirmed the two
    figures came from different slicer profiles. Both mentions now say so,
    and the materials row no longer claims near-identical volume while the
    table above it shows a 14 cm³ difference. PETG keeps its
    not-yet-strength-tested caution per the designer's call.
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2026-09-23 docs: match print minimums to Slant 3D's actual Teleport profile
    The order page claimed Slant prints 6 walls / 35% 3D honeycomb / 2 mm;
    Slant's Teleport uses one fixed profile (0.2 mm layers, 1 mm walls on
    every face, 25% grid infill). George removed those rows in June; they
    were wrongly restored on 2026-07-30. The guides also banned grid and
    required 2 mm top/bottom, so the units we sell fell below our own
    stated minimum. Per George: drop the honeycomb preference, allow any
    non-concentric infill (grid OK), top/bottom minimum 1 mm.
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
